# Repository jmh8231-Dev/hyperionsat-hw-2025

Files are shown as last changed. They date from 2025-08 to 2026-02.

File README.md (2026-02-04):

# HyperionSAT Flight‑Computer – 하드웨어 (2025)

> **Rev**: 1.0 · **ECAD**: KiCad 9.0.4 · **MCU**: STM32H723VGT6 (550 MHz, DP‑FPU)  
> **역할**: 2차 추진, TVC 제어, 센싱, 통신을 담당하는 하이브리드 비행 컴퓨터

---

<h3>3D Rendering</h3>
<table>
  <tr>
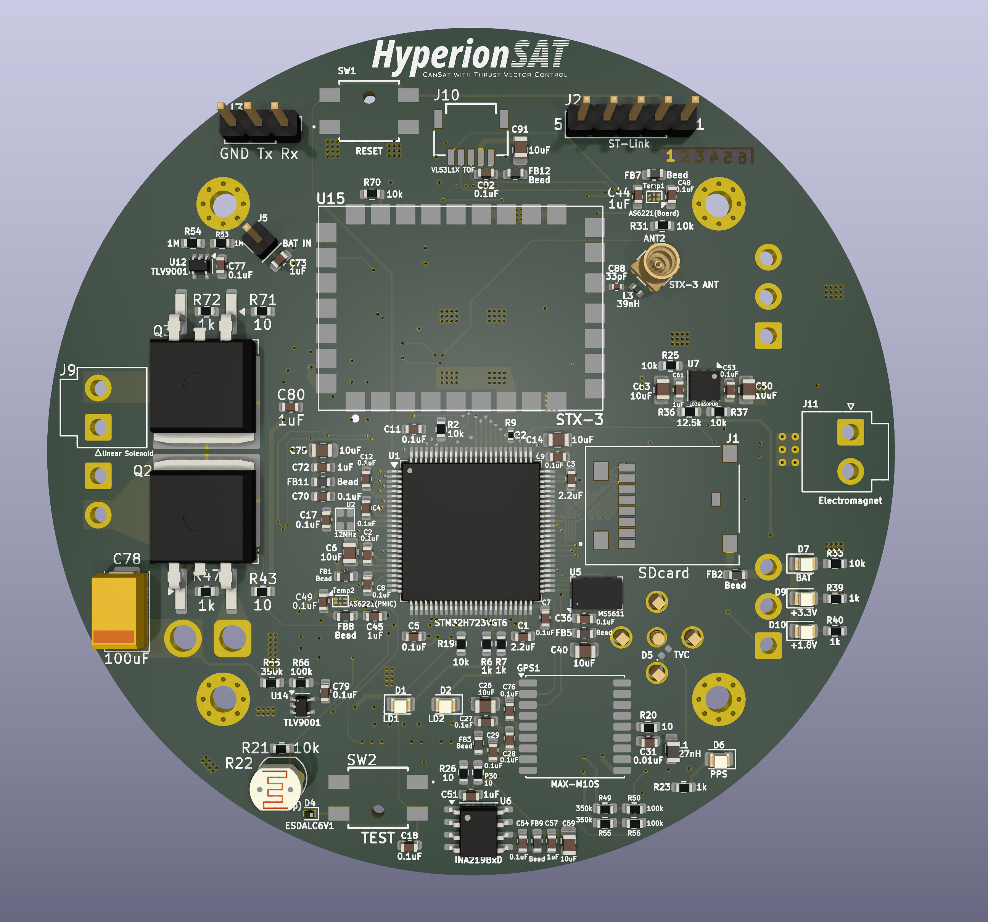
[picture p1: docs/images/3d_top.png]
Top
    <td></td>
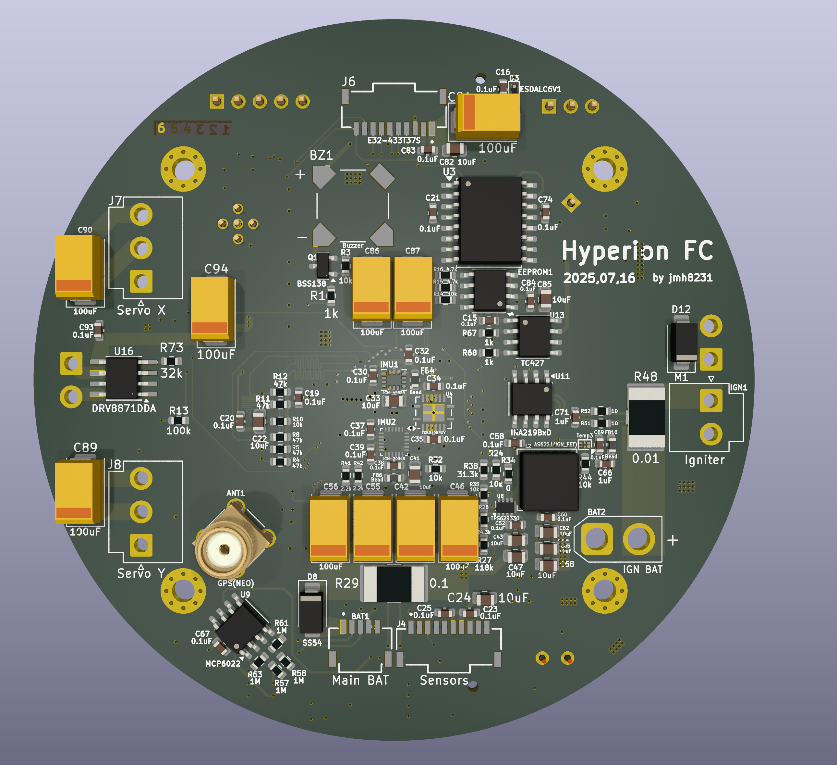
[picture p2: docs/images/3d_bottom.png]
Bottom
    <td></td>
  </tr>
  <tr>
    <td align="center"><sub>Top</sub></td>
    <td align="center"><sub>Bottom</sub></td>
  </tr>

  <tr>
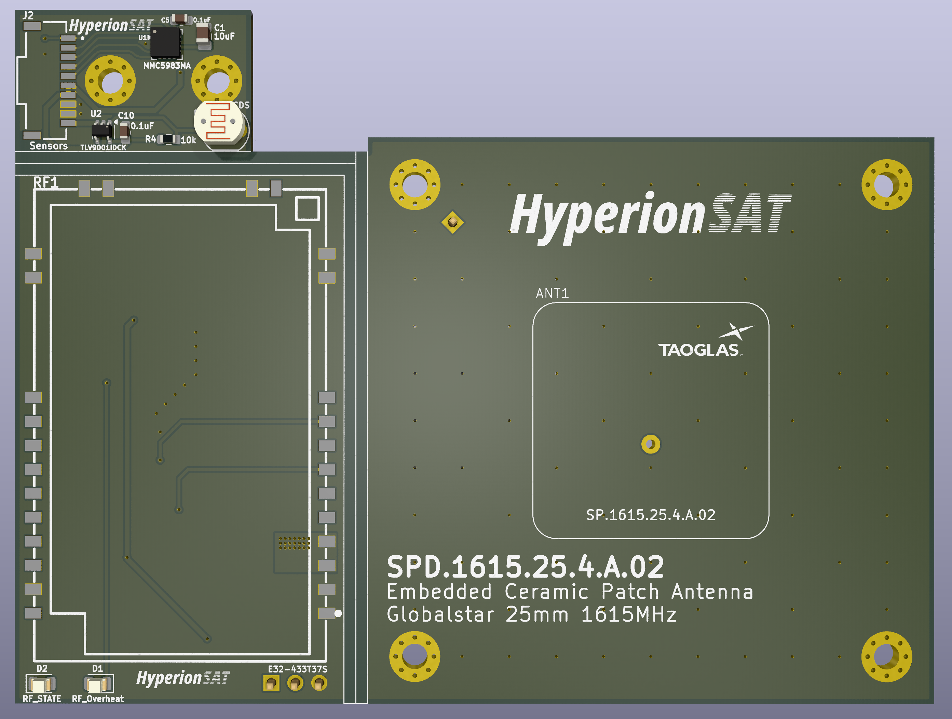
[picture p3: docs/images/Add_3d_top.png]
SUB Top
    <td></td>
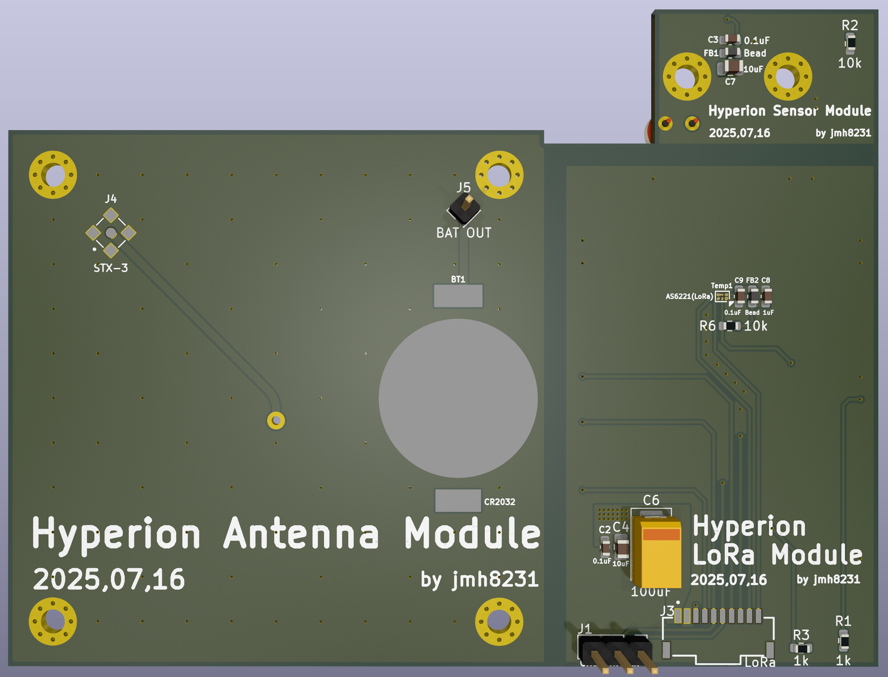
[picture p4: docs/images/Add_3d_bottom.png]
SUB Bottom
    <td></td>
  </tr>
  <tr>
    <td align="center"><sub>SUB Top</sub></td>
    <td align="center"><sub>SUB Bottom</sub></td>
  </tr>
</table>

---

## 리포지토리 구성 (스냅샷)
```
docs/
└─ images/
   ├─ sch_processor.png
   ├─ sch_sensors.png
   ├─ sch_pmic.png
   ├─ sch_comm.png
   ├─ sch_actuators.png
   └─ sch_additional.png
README.md
```

---

## 1) 시스템 개요

**블록**
- **Processor**: STM32H723VGT6, 12 MHz TCXO, SWD, EEPROM(AT24C08C), RTC(DS3231M), Buzzer/LED, microSD(SDMMC 4‑bit).
- **Flight Sensors**: ICM‑45686(SPI), ICM‑20948(SPI, 1.8 V IO), MS5611(SPI), MMC5983MA(SPI), MAX‑M10S(UART+PPS), VL53L1X(I²C), **CDS‑Top/Bottom**(Bottom=TLV9001 버퍼).
- **Actuators**: TVC 서보 X/Y(12 V), **리니어 솔레노이드**(IRF1404, 어댑터 분리), **낙하산 전개 전자석**(DRV8871DDA).
- **Communications**: LoRa E32‑433T37S(UART + M0/M1/AUX), **Globalstar STX‑3**(UART + EN/RESET), RF 매칭 네트워크.
- **PMIC/Power**: 메인 Li‑Po 3S(셀1/2 버퍼드 ADC), **점화 배터리**(팩 전압 ADC), 3.3 V 스위칭, **INA219** 방전/점화 전류 측정, **AS6221** 온도.

**점화(IGN)**: **1채널** 구성으로 단순화됨.

<h3>Block Diagrams</h3>
<table>
  <tr>
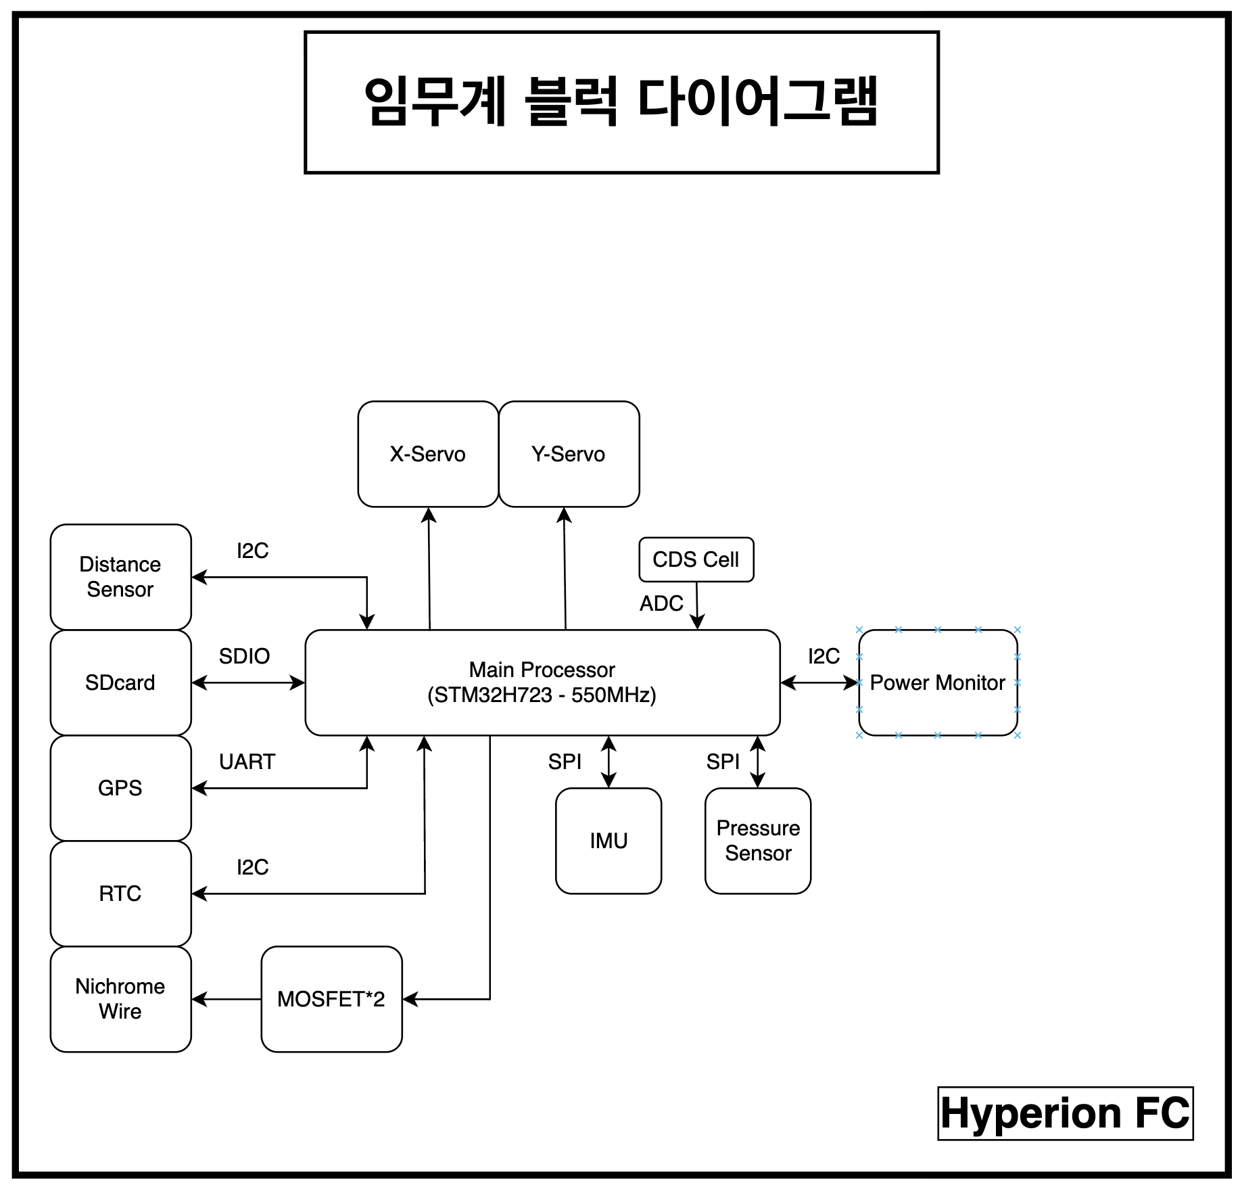
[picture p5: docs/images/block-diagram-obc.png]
OBC
    <td></td>
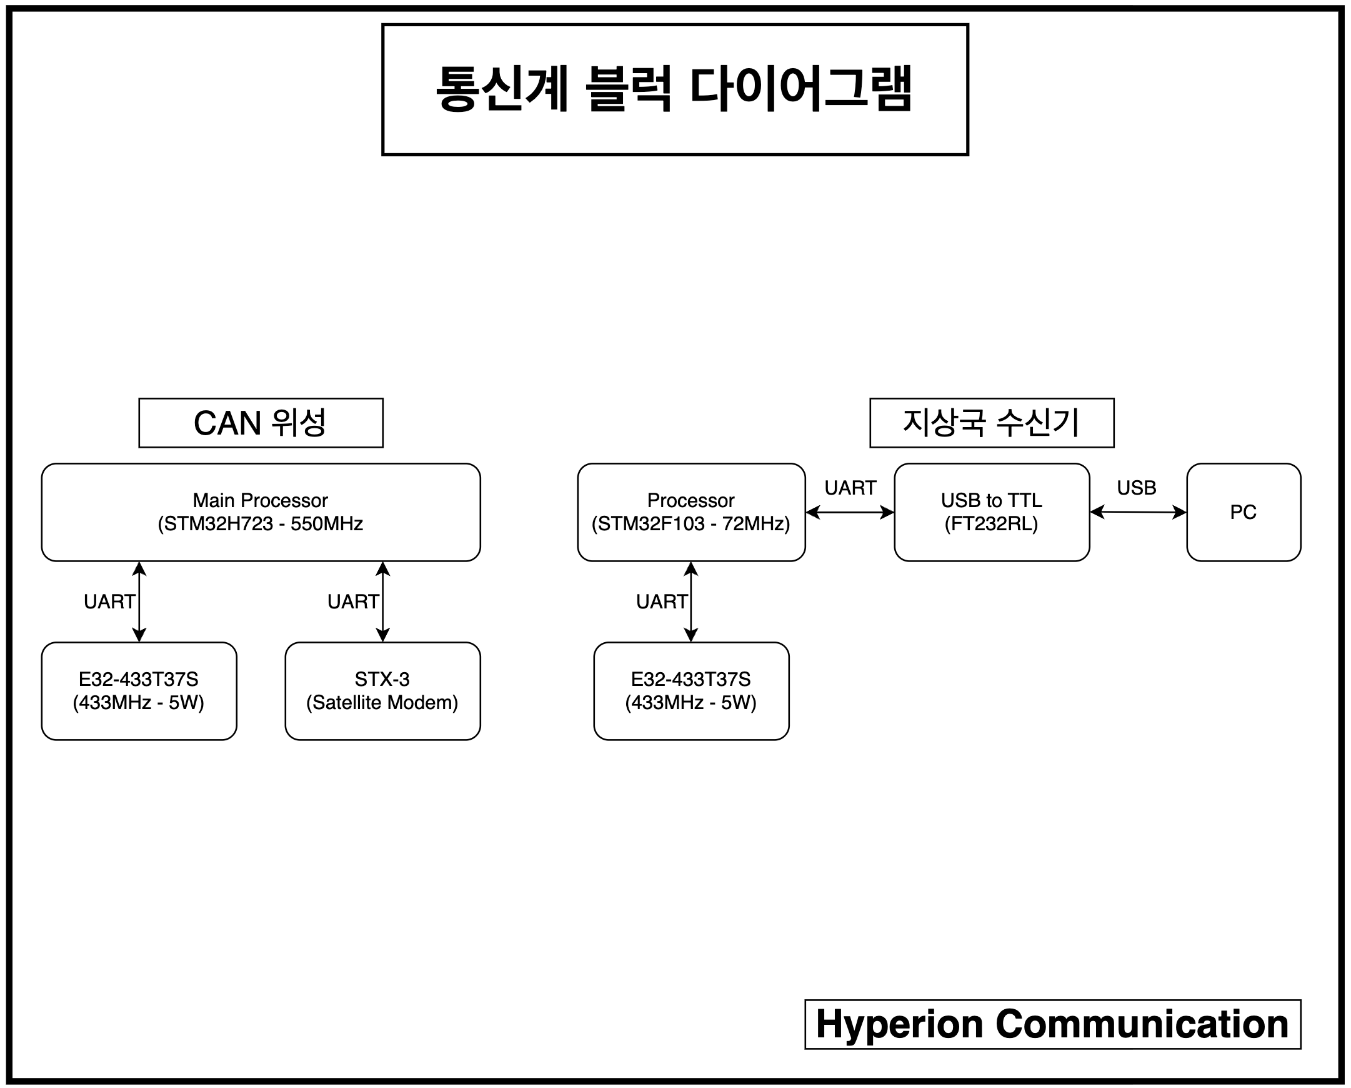
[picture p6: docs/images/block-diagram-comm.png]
Communication
    <td></td>
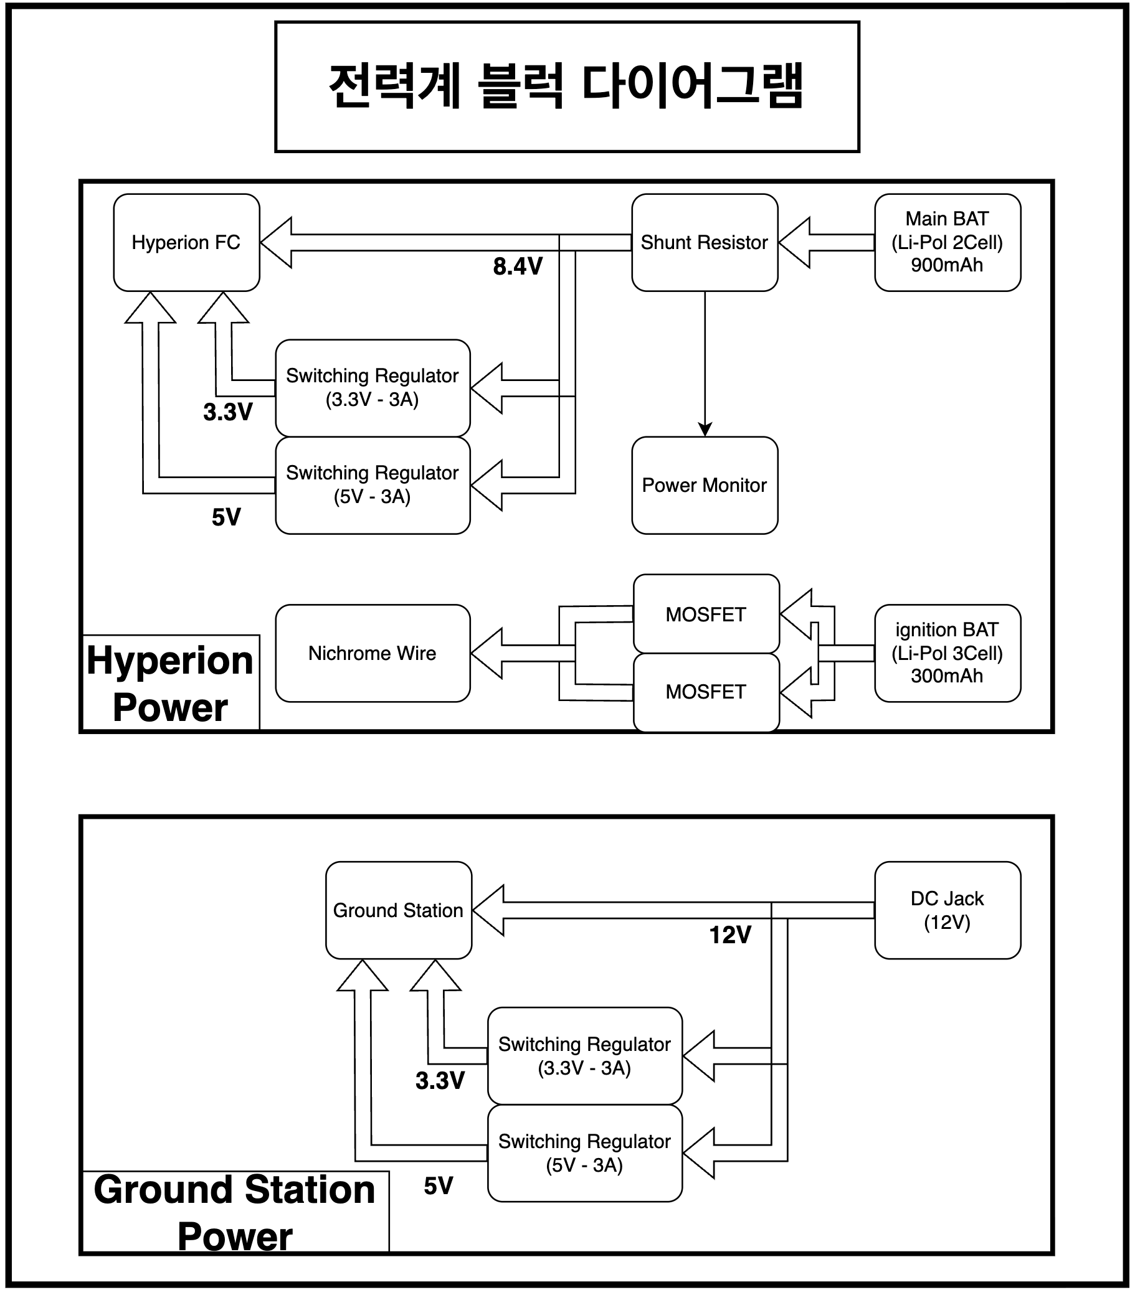
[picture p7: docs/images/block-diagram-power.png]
Power
    <td></td>
  </tr>
  <tr>
    <td align="center"><sub>OBC</sub></td>
    <td align="center"><sub>Communication</sub></td>
    <td align="center"><sub>Power</sub></td>
  </tr>
</table>

---

## 2) 전기적 인터페이스 (네트 라벨 기준)

### SPI
| Bus | Device | Signals |
|---|---|---|
| SPI‑A | ICM‑45686 | `ICM-45686_SCK/MISO/MOSI/CS`, `ICM-45686_INT` |
| SPI‑B | ICM‑20948, MS5611 | `ICM-20948_SCK/MISO/MOSI/CS`, `IMU2_INT`; `Barometer_SCK/MISO/MOSI/CS` |
| SPI‑C | MMC5983MA | `MMC5983MA_SCK/MISO/MOSI/CS`, `MMC5983MA_INT` |

### I²C (7‑bit)
| Bus | Device | Addr |
|---|---|---|
| RTC | DS3231M | 0x68 |
| EEPROM | AT24C08C | 0x50 *(데이터시트 8‑bit 코드 0xA0)* |
| TEMP | AS6221(Board/PMIC/FET/LoRa) | 0x48 / 0x49 / 0x4B / 0x4A |
| IGN | INA219 | 0x41 |

### UART / 타이밍 / GPIO
| Link | Signals |
|---|---|
| Debug | `Debug_Tx`, `Debug_Rx` |
| LoRa(E32) | `RF_Tx`, `RF_Rx`, `RF_M0`, `RF_M1`, `RF_AUX` |
| STX‑3 | `STX-3_Tx`, `STX-3_Rx`, `STX-3_CTS`, `STX-3_RTS`, `STX-3_EN`, `STX-3_Reset` |
| GPS | `GPS_Tx`, `GPS_Rx`, `GPS_PPS` |
| SDMMC | `SDMMC_D0..D3`, `SDMMC_CLK`, `SDMMC_CMD`, `SDMMC_DET`, `SDMMC_WP` |
| Actuators | `Servo_X`, `Servo_Y`, `Solenoid_Gate`, `DRV8871_A`, `DRV8871_B` |
| Analog | `Main_Cell1_ADC`, `Main_Cell2_ADC`, `IGN_BAT_ADC`, `Back-up_BAT_ADC`, `CDS_Top`, `CDS_Bottom_ADC` |

---

## 3) 회로도 스냅샷

- **Processor**  
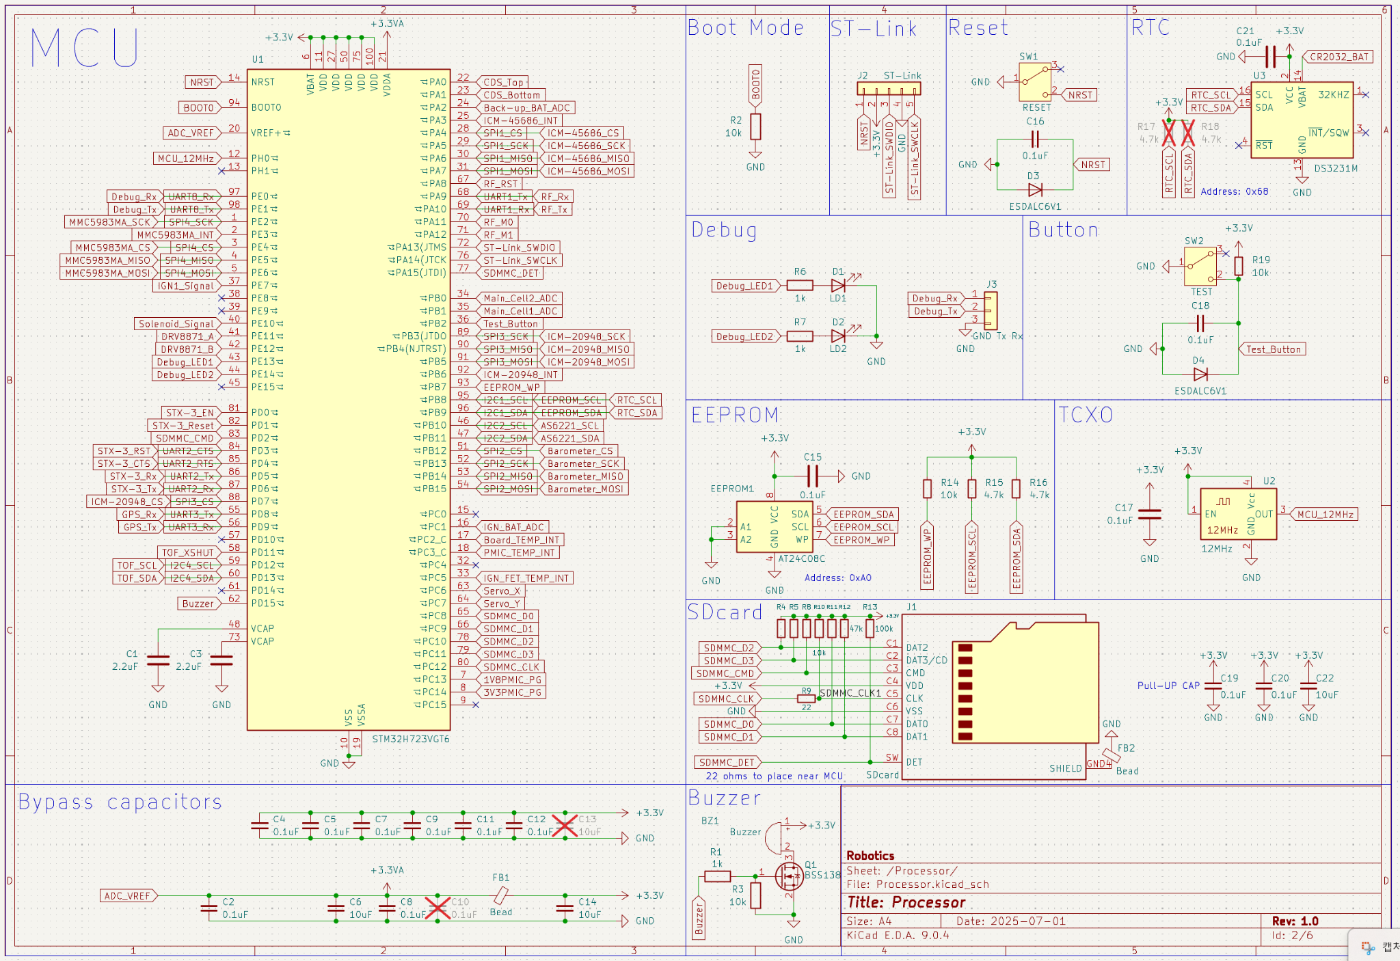
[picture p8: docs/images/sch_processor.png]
  

- **Flight Sensors**  
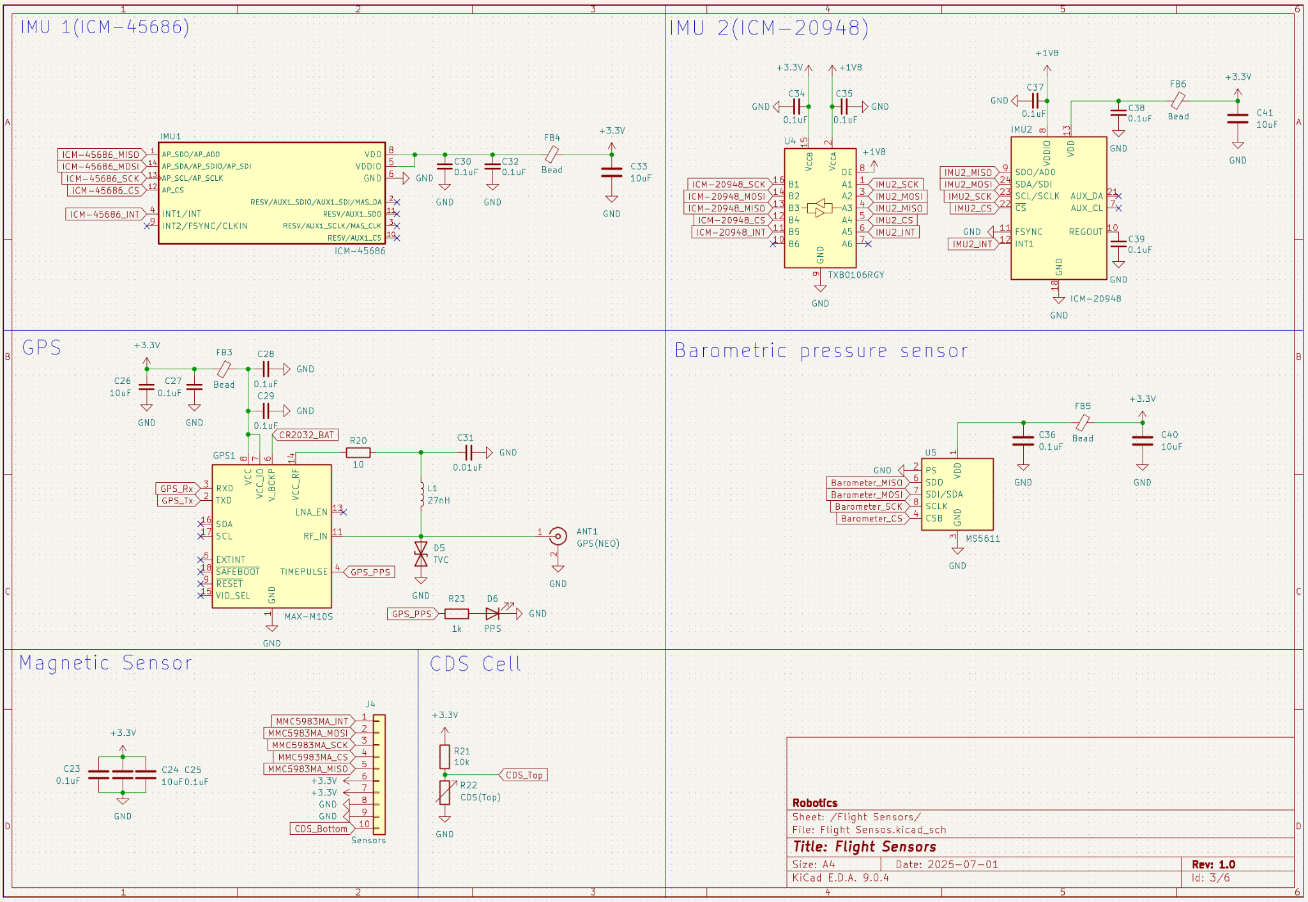
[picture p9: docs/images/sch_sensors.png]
  

- **PMIC / Power**  
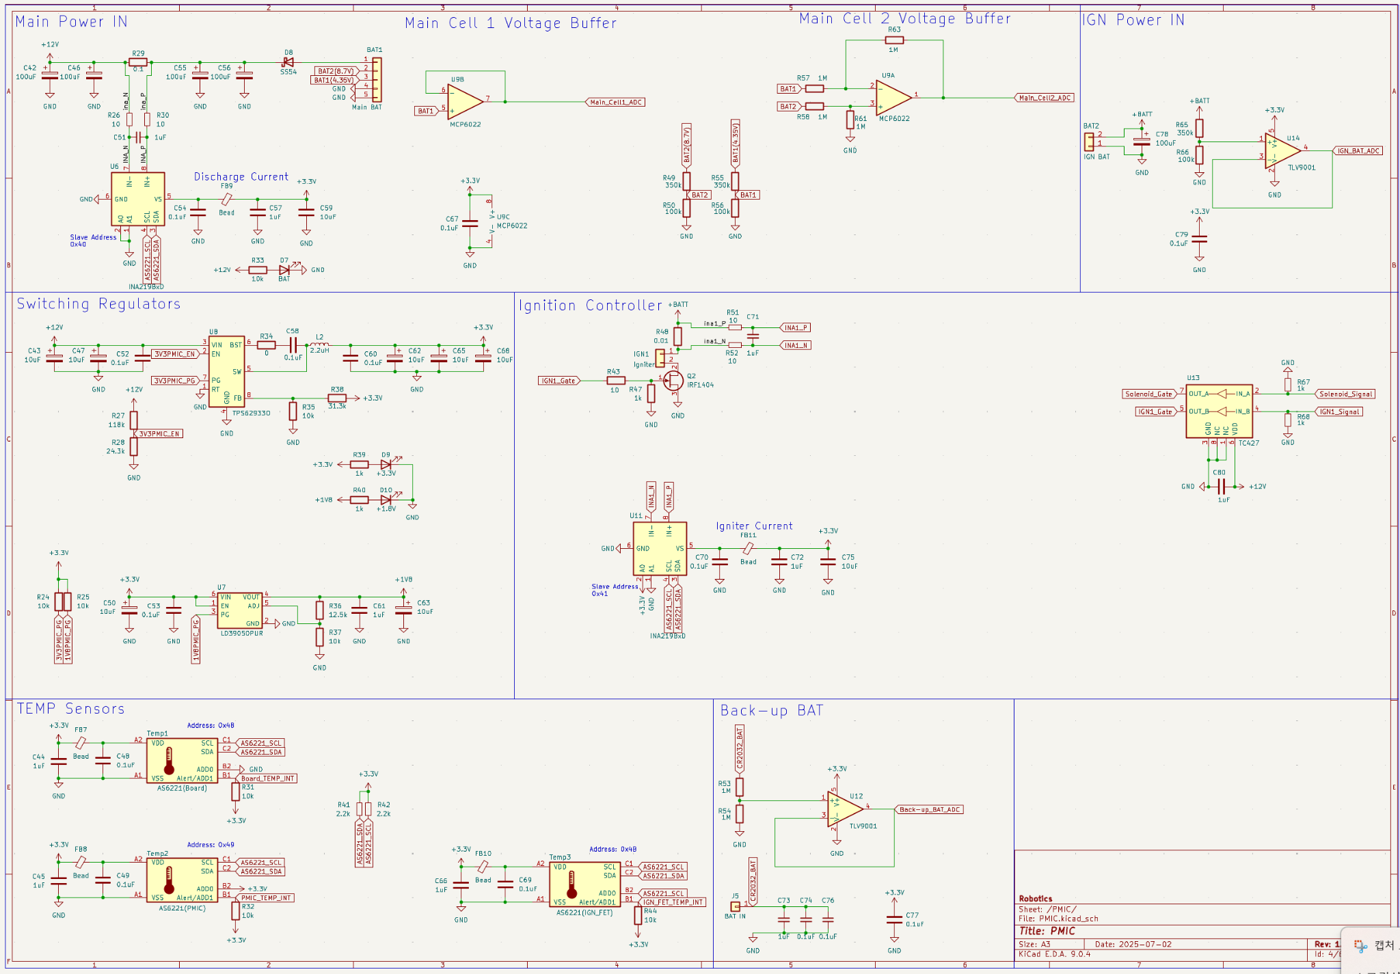
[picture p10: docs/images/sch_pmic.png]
  

- **Communications**  
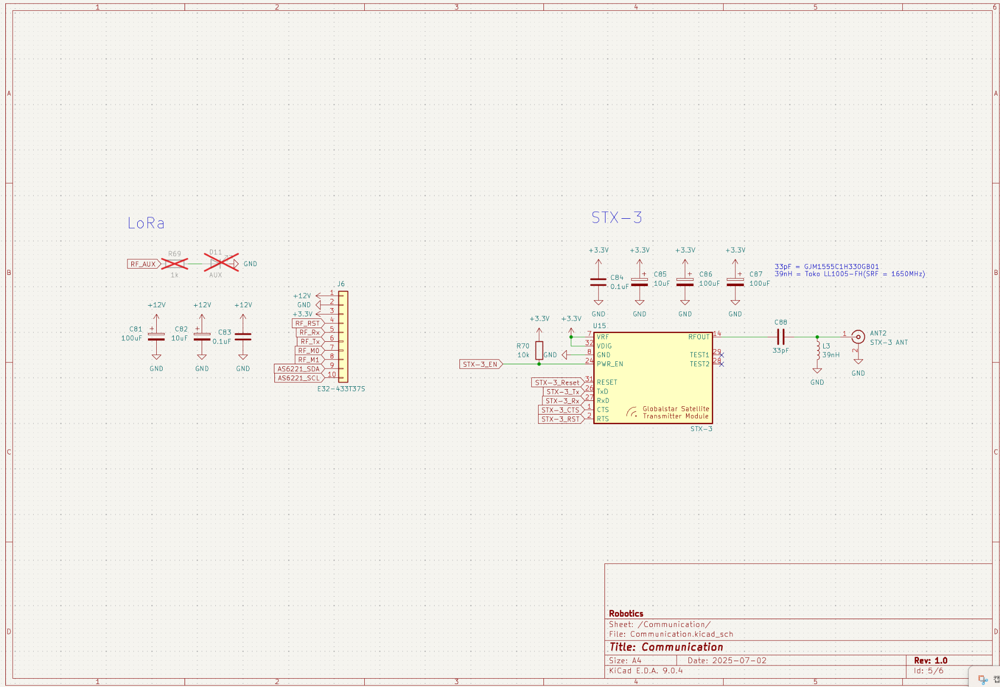
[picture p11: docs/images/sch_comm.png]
  

- **Actuators**  
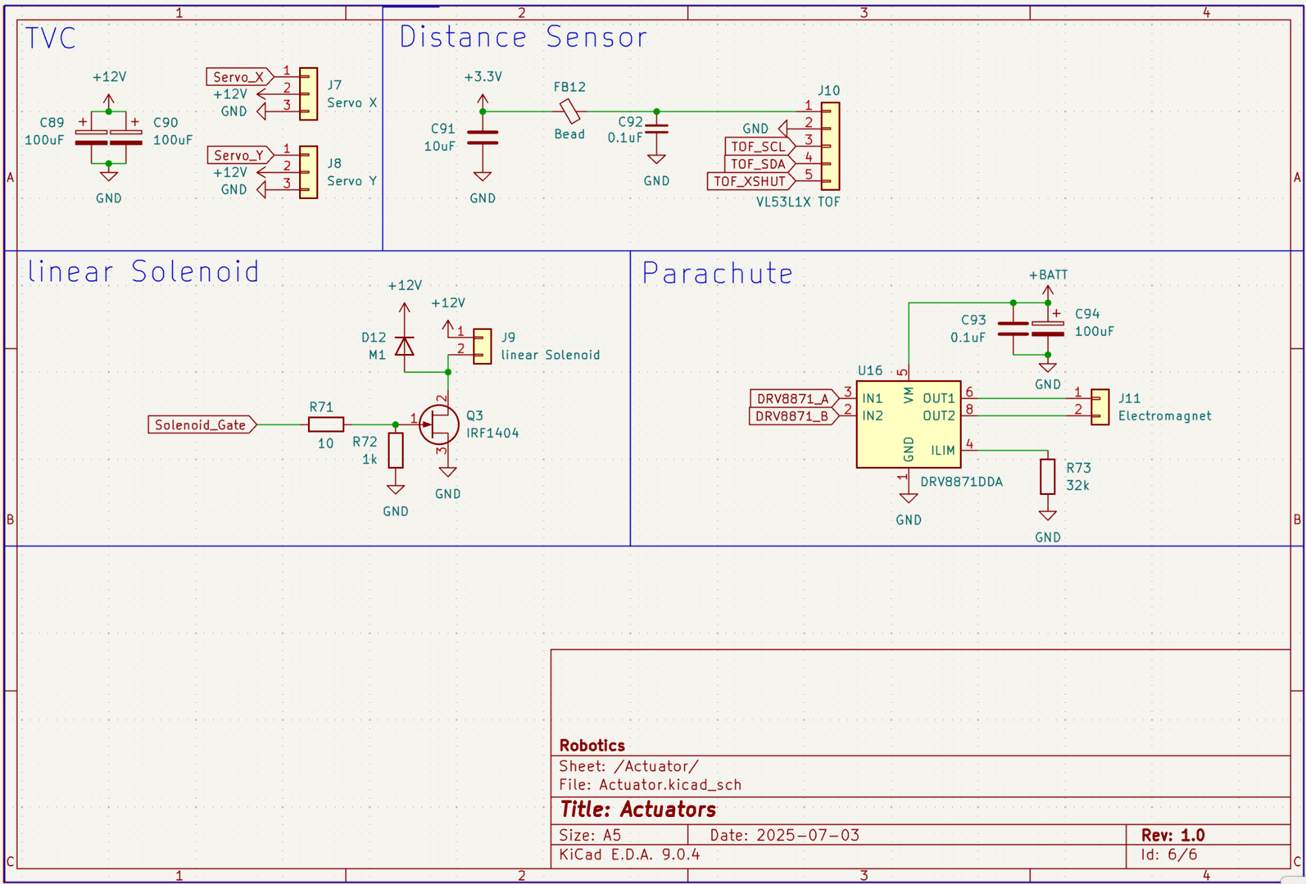
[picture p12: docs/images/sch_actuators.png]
  

- **Additional parts (Magnetometer SPI, CDS Bottom 버퍼, LoRa 온도)**  
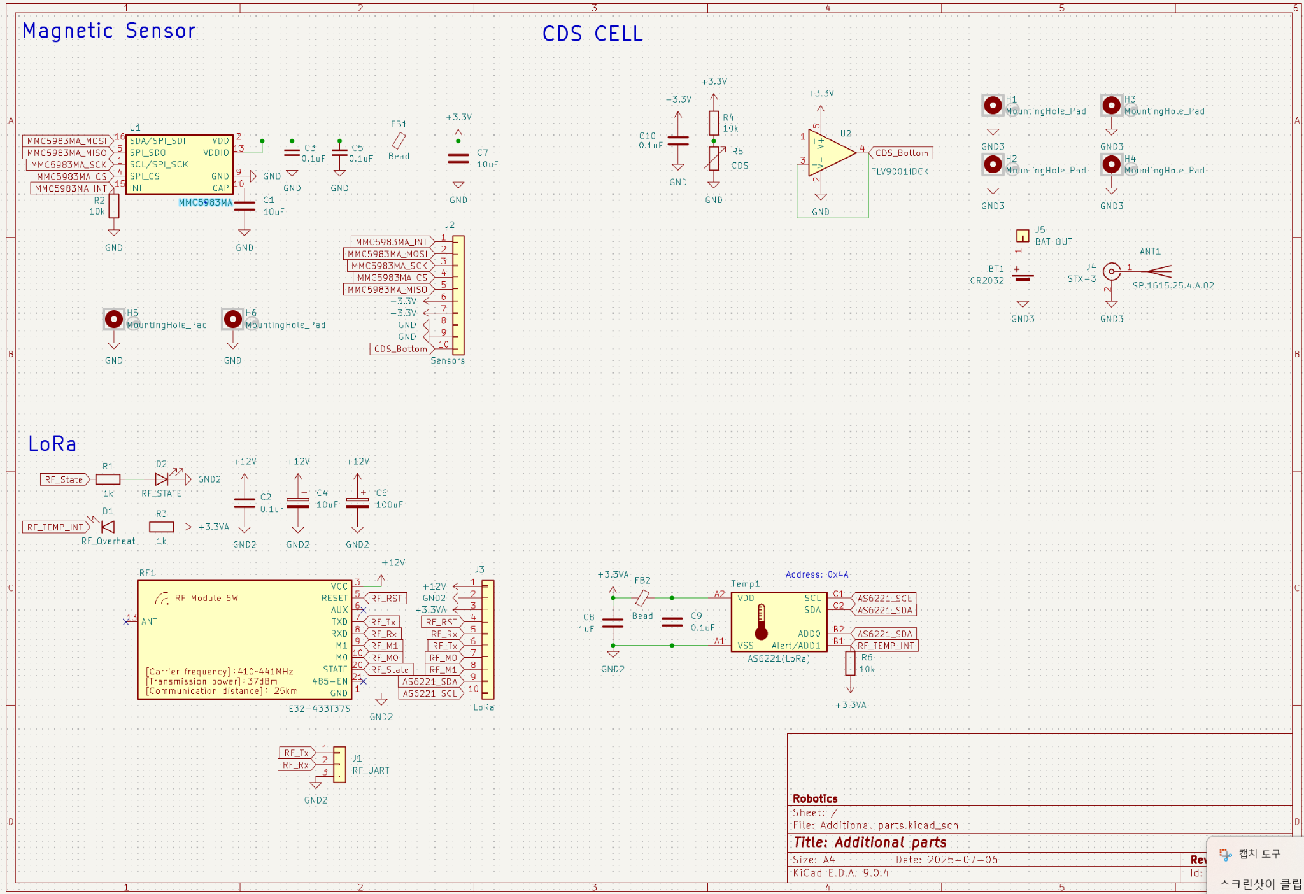
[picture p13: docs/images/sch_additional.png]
  

> **Firmware repo**: [https://github.com/ORG/REPO-FW  ](https://github.com/jmh8231-Dev/hyperionsat-fw-2025)

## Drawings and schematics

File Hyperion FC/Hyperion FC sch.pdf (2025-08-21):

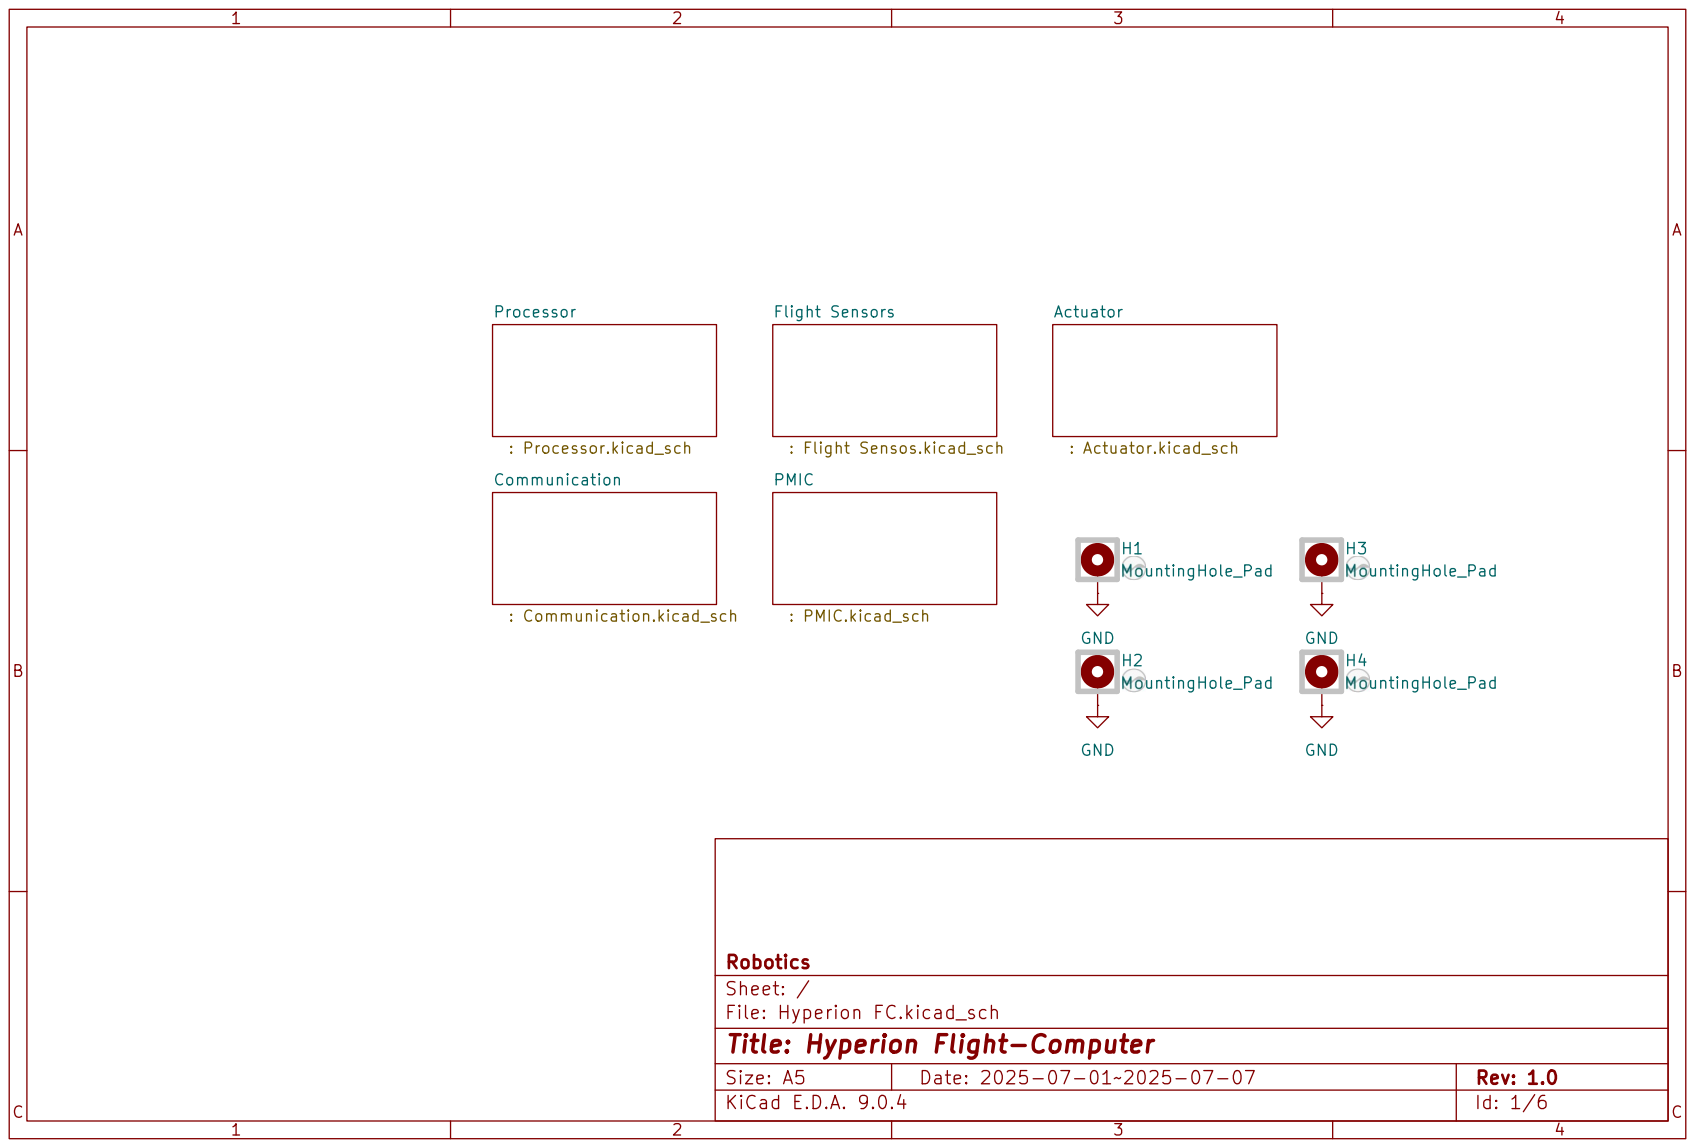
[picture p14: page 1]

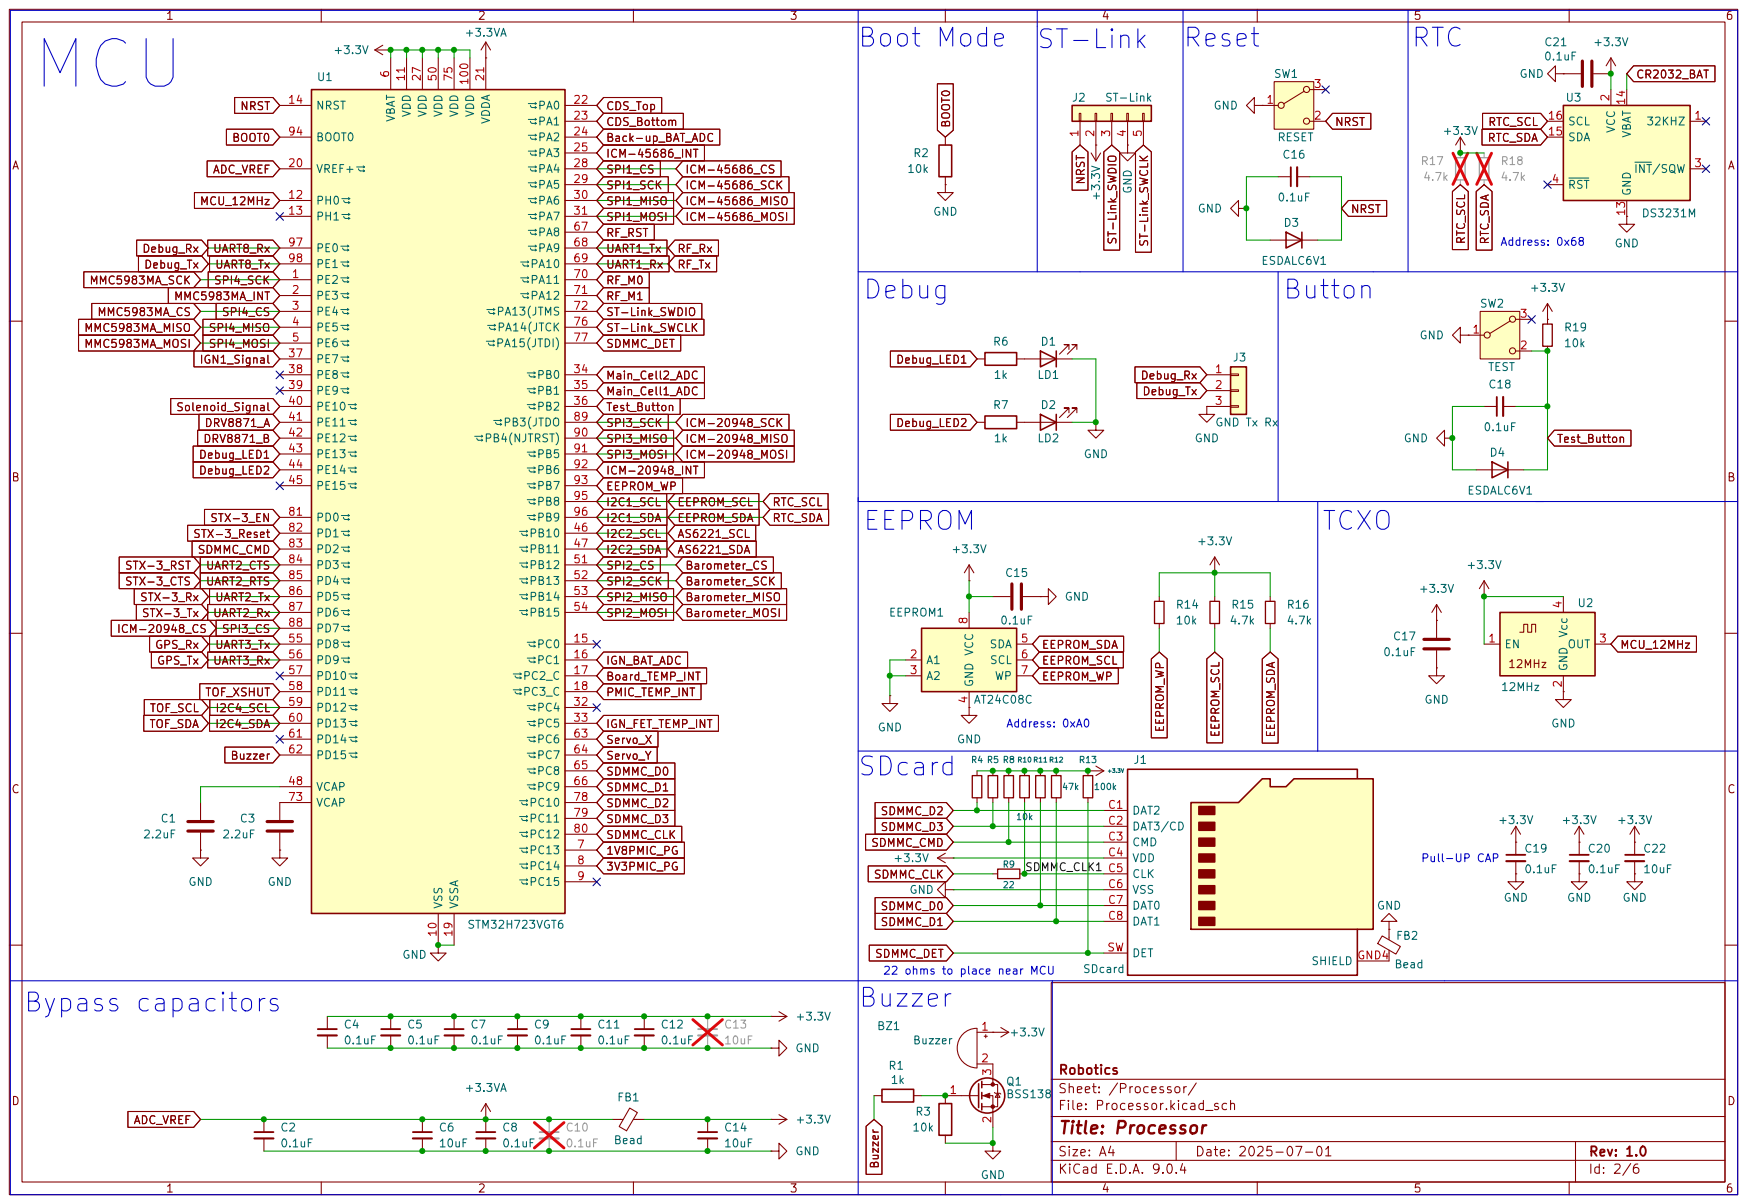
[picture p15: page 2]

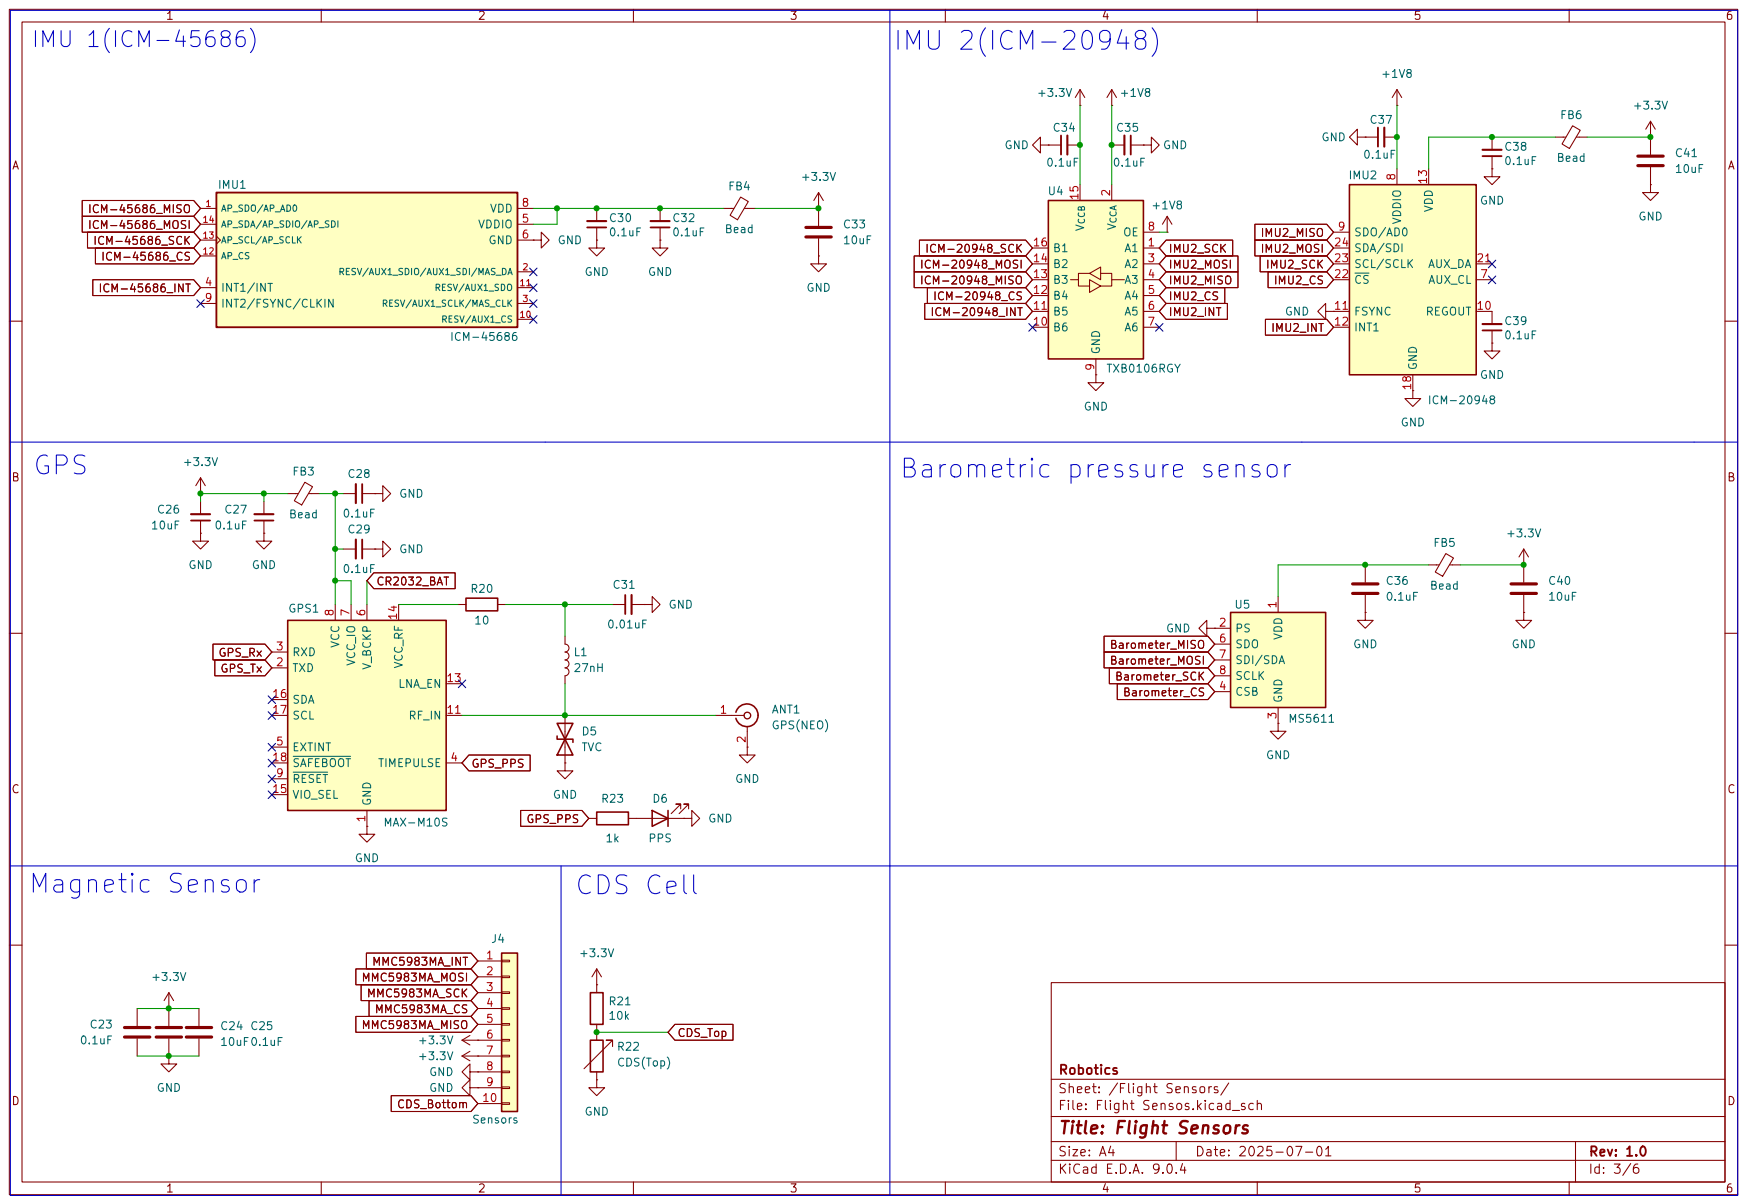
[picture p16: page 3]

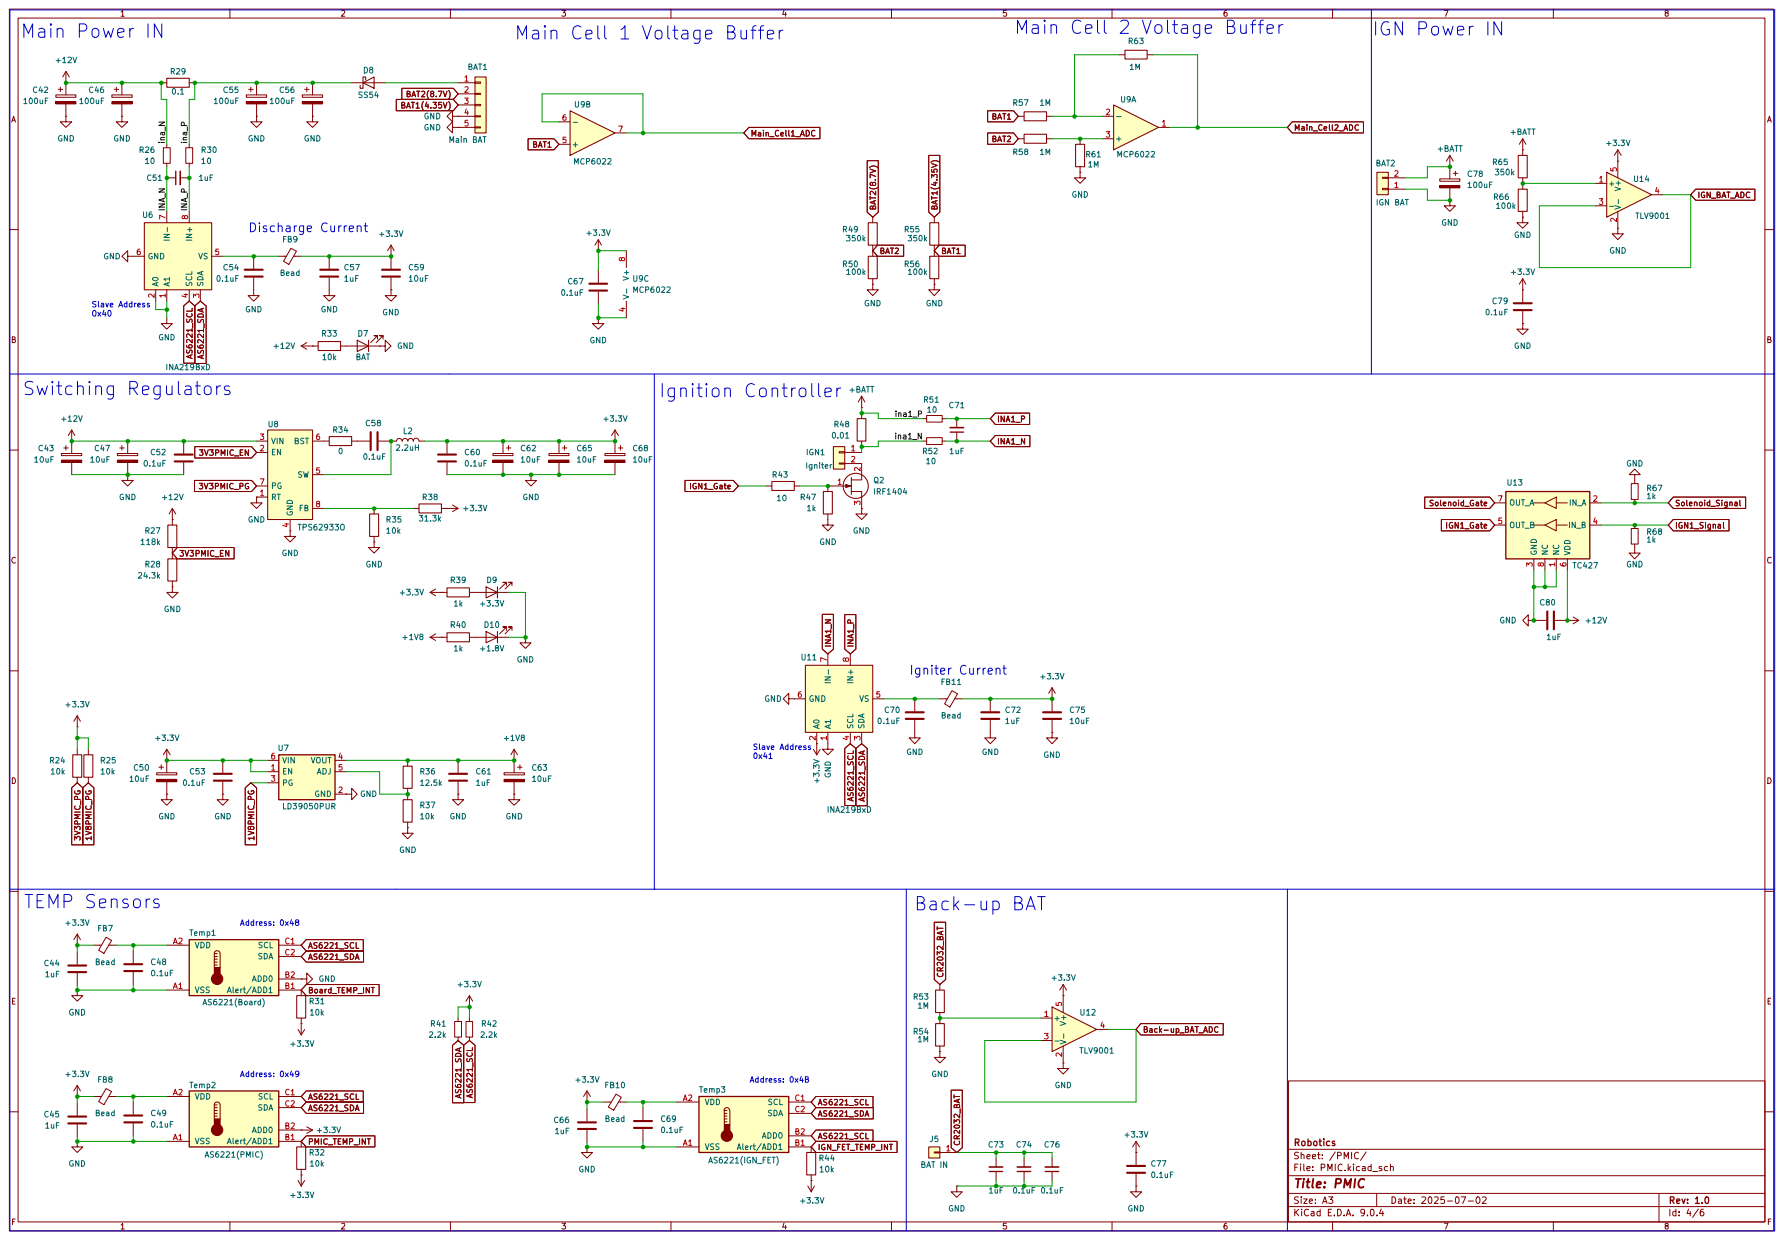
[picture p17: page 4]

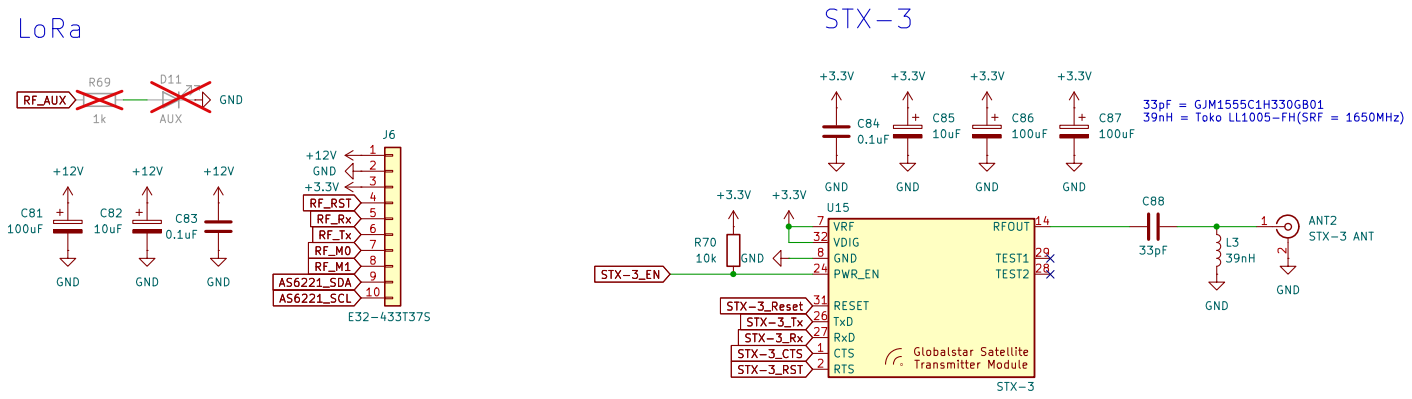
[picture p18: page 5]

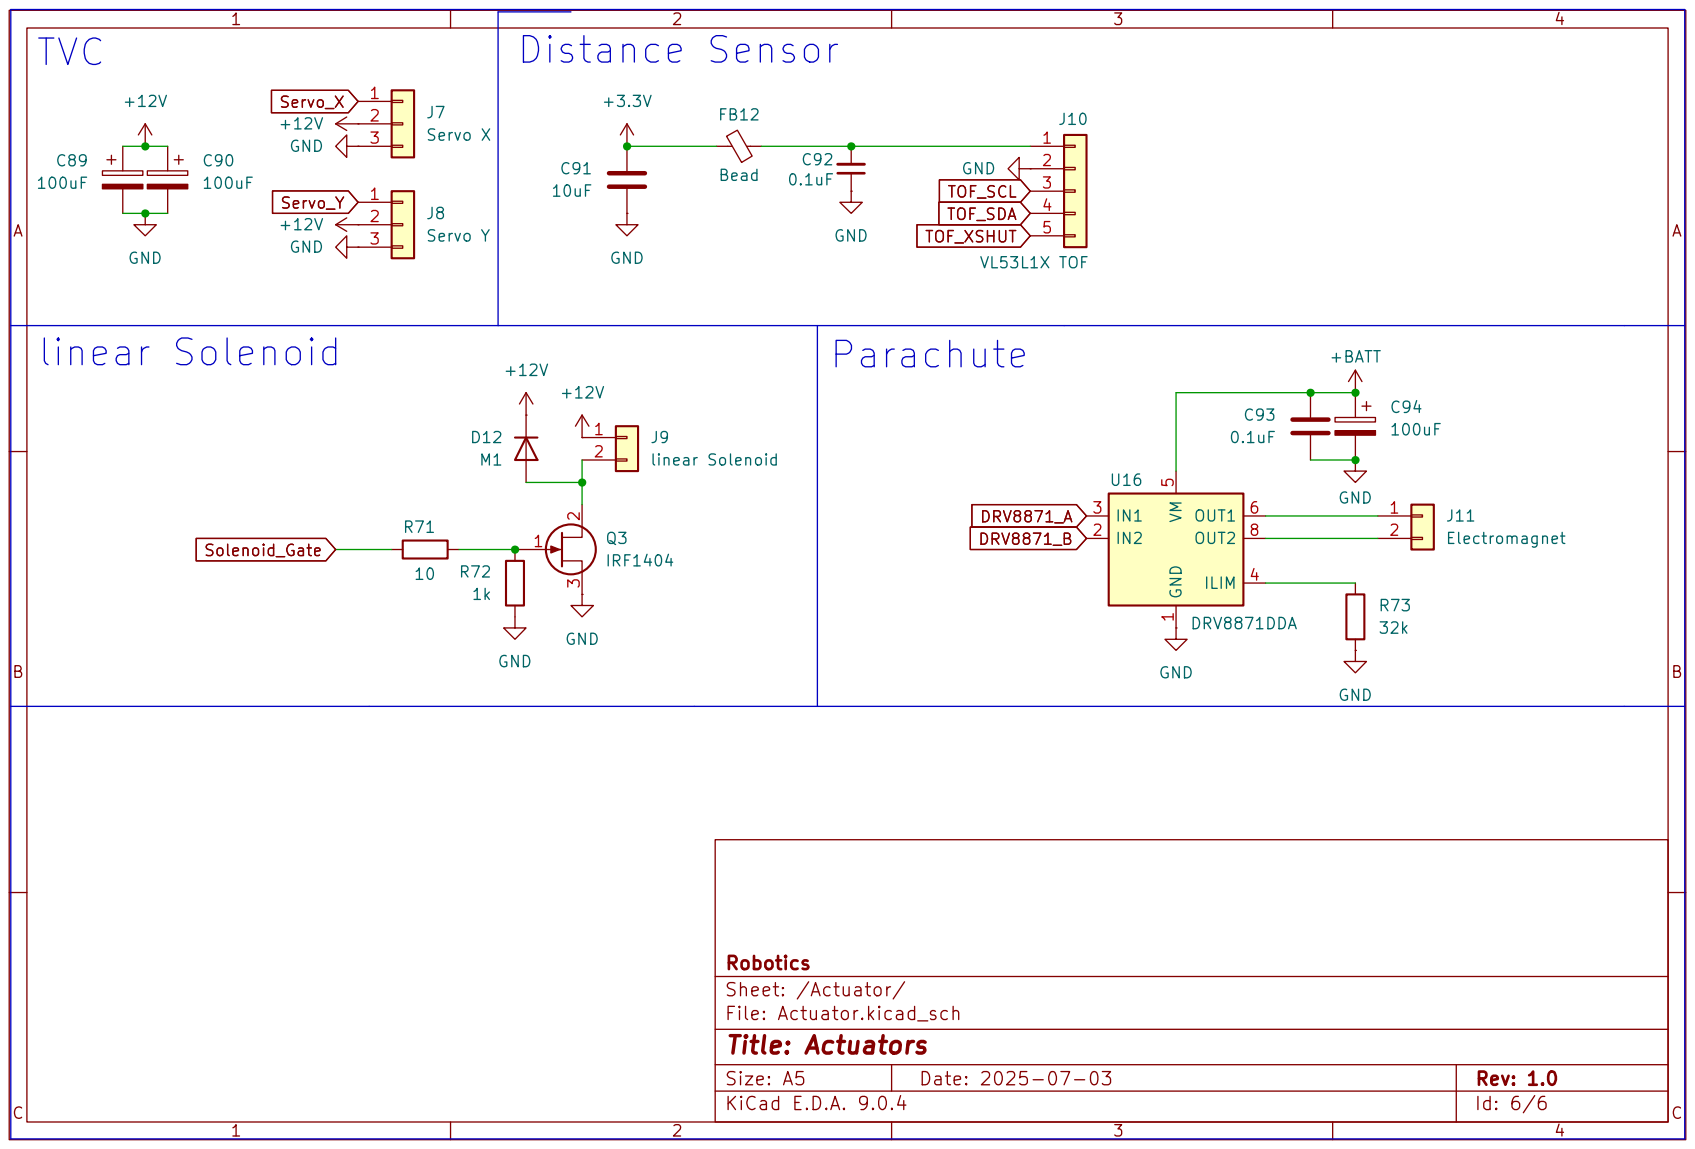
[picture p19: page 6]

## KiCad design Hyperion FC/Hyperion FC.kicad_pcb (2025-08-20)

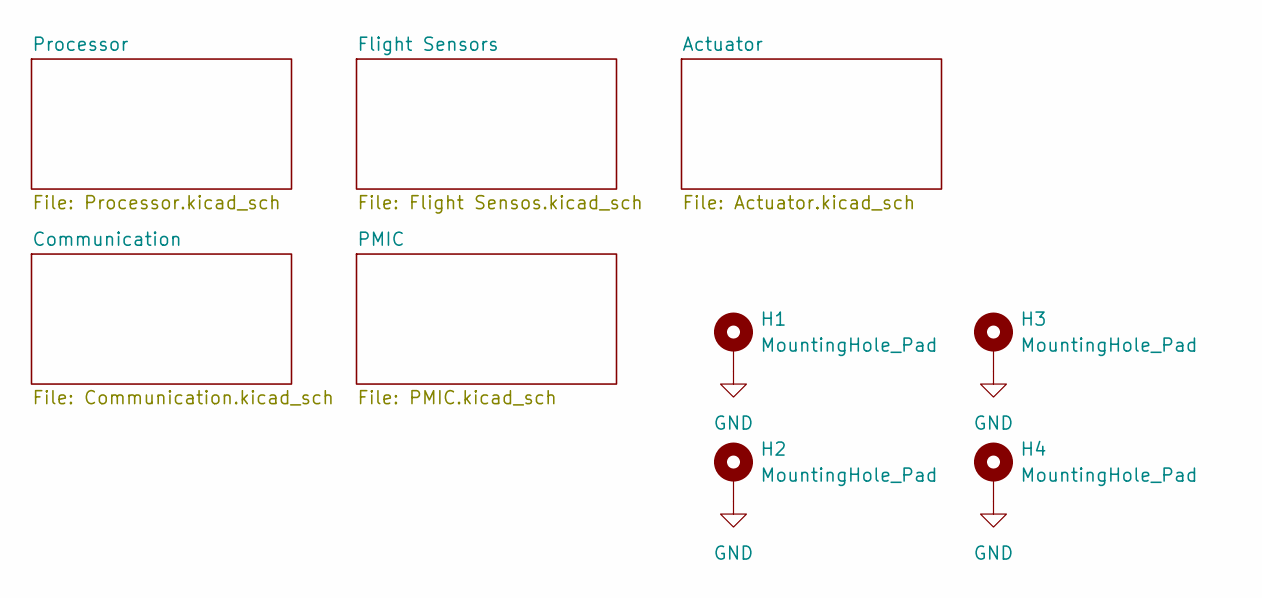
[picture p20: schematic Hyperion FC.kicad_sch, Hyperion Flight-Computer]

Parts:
H1, H2, H3, H4: MountingHole_Pad; MountingHole_2.7mm_M2.5_Pad_Via

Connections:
GND: H1.1, H2.1, H3.1, H4.1; also elsewhere on the board

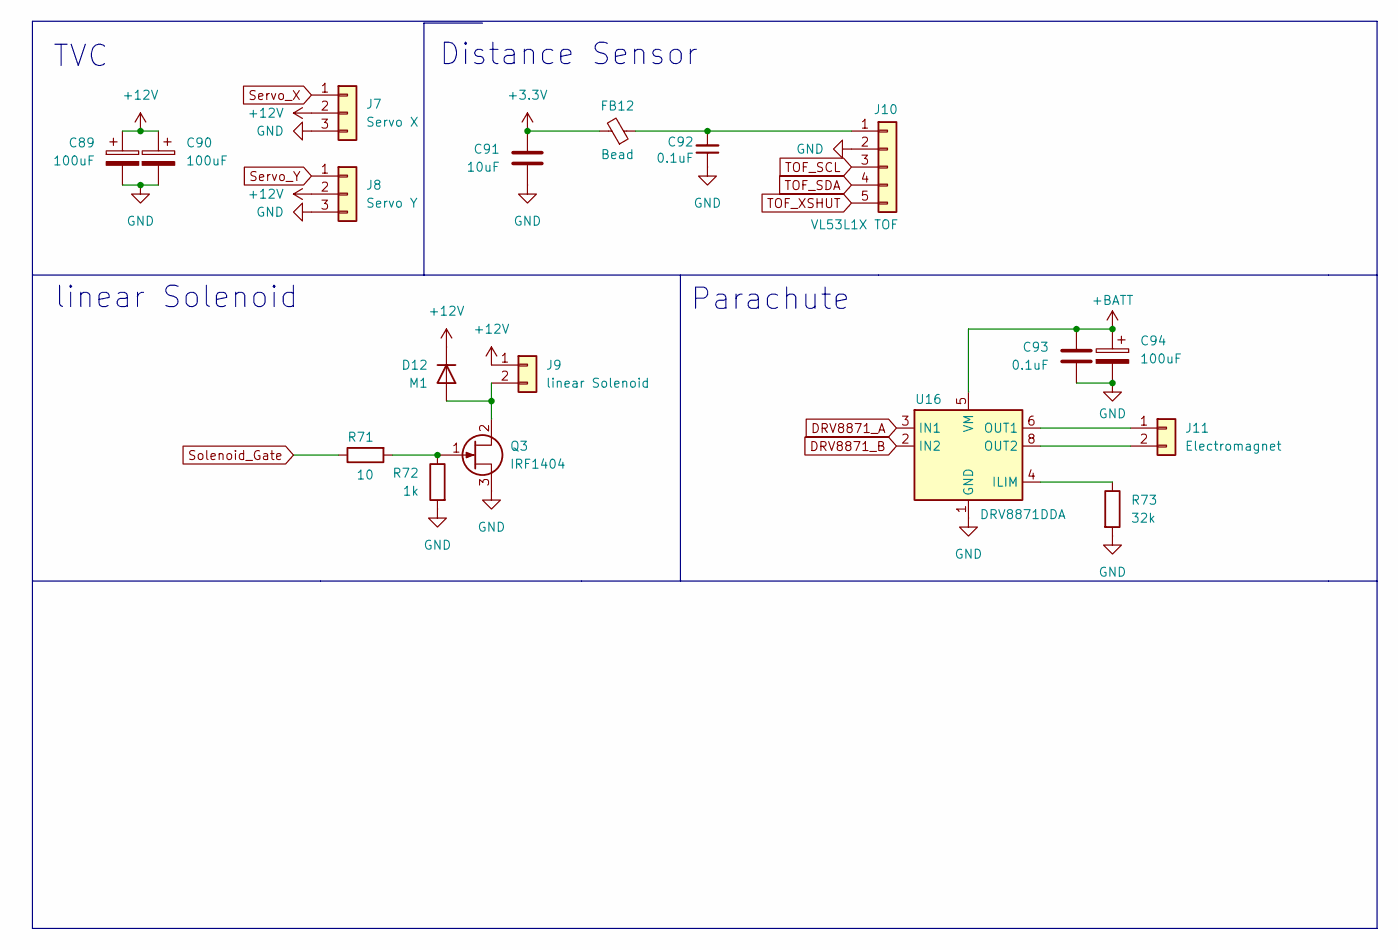
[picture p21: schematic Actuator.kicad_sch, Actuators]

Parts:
C89, C90, C94: 100uF; CP_EIA-7343-43_Kemet-X
C91: 10uF; C_0805_2012Metric
C92, C93: 0.1uF; C_0603_1608Metric
D12: M1; D_SMA
FB12: Bead; L_0603_1608Metric
J7: Servo X; JST_VH_B3P-VH_1x03_P3.96mm_Vertical
J8: Servo Y; JST_VH_B3P-VH_1x03_P3.96mm_Vertical
J9: linear Solenoid; JST_VH_B2P-VH_1x02_P3.96mm_Vertical
J10: VL53L1X TOF; SAMTEC_T1M-05-F-SH-L
J11: Electromagnet; JST_VH_B2P-VH_1x02_P3.96mm_Vertical
Q3: IRF1404; TO-263-2
R71: 10; R_0603_1608Metric
R72: 1k; R_0603_1608Metric
R73: 32k; R_0603_1608Metric
U16: DRV8871DDA; Texas_HTSOP-8-1EP_3.9x4.9mm_P1.27mm_EP2.95x4.9mm_Mask2.4x3.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

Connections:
+3.3V: C91.1, FB12.2; also elsewhere on the board
+12V: C89.1, C90.1, D12.1 (K), J7.2, J8.2, J9.1; also elsewhere on the board
+BATT: C93.1, C94.1, U16.5 (VM); also elsewhere on the board
DRV8871_A: U16.3 (IN1); also elsewhere on the board
DRV8871_B: U16.2 (IN2); also elsewhere on the board
GND: C89.2, C90.2, C91.2, C92.1, C93.2, C94.2, J7.3, J8.3, J10.2, Q3.3 (S), R72.2, R73.2, U16.1 (GND), U16.7 (GND), U16.9 (GND); also elsewhere on the board
I2C4_SCL: J10.3; also elsewhere on the board
I2C4_SDA: J10.4; also elsewhere on the board
unnamed: D12.2 (A), J9.2, Q3.2 (D)
unnamed: C92.2, FB12.1, J10.1
unnamed: J11.1, U16.6 (OUT1)
unnamed: J11.2, U16.8 (OUT2)
unnamed: Q3.1 (G), R71.2, R72.1
unnamed: R73.1, U16.4 (ILIM)
Servo_X: J7.1; also elsewhere on the board
Servo_Y: J8.1; also elsewhere on the board
Solenoid_Gate: R71.1; also elsewhere on the board
TOF_XSHUT: J10.5; also elsewhere on the board

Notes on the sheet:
linear Solenoid
Parachute
TVC
Distance Sensor

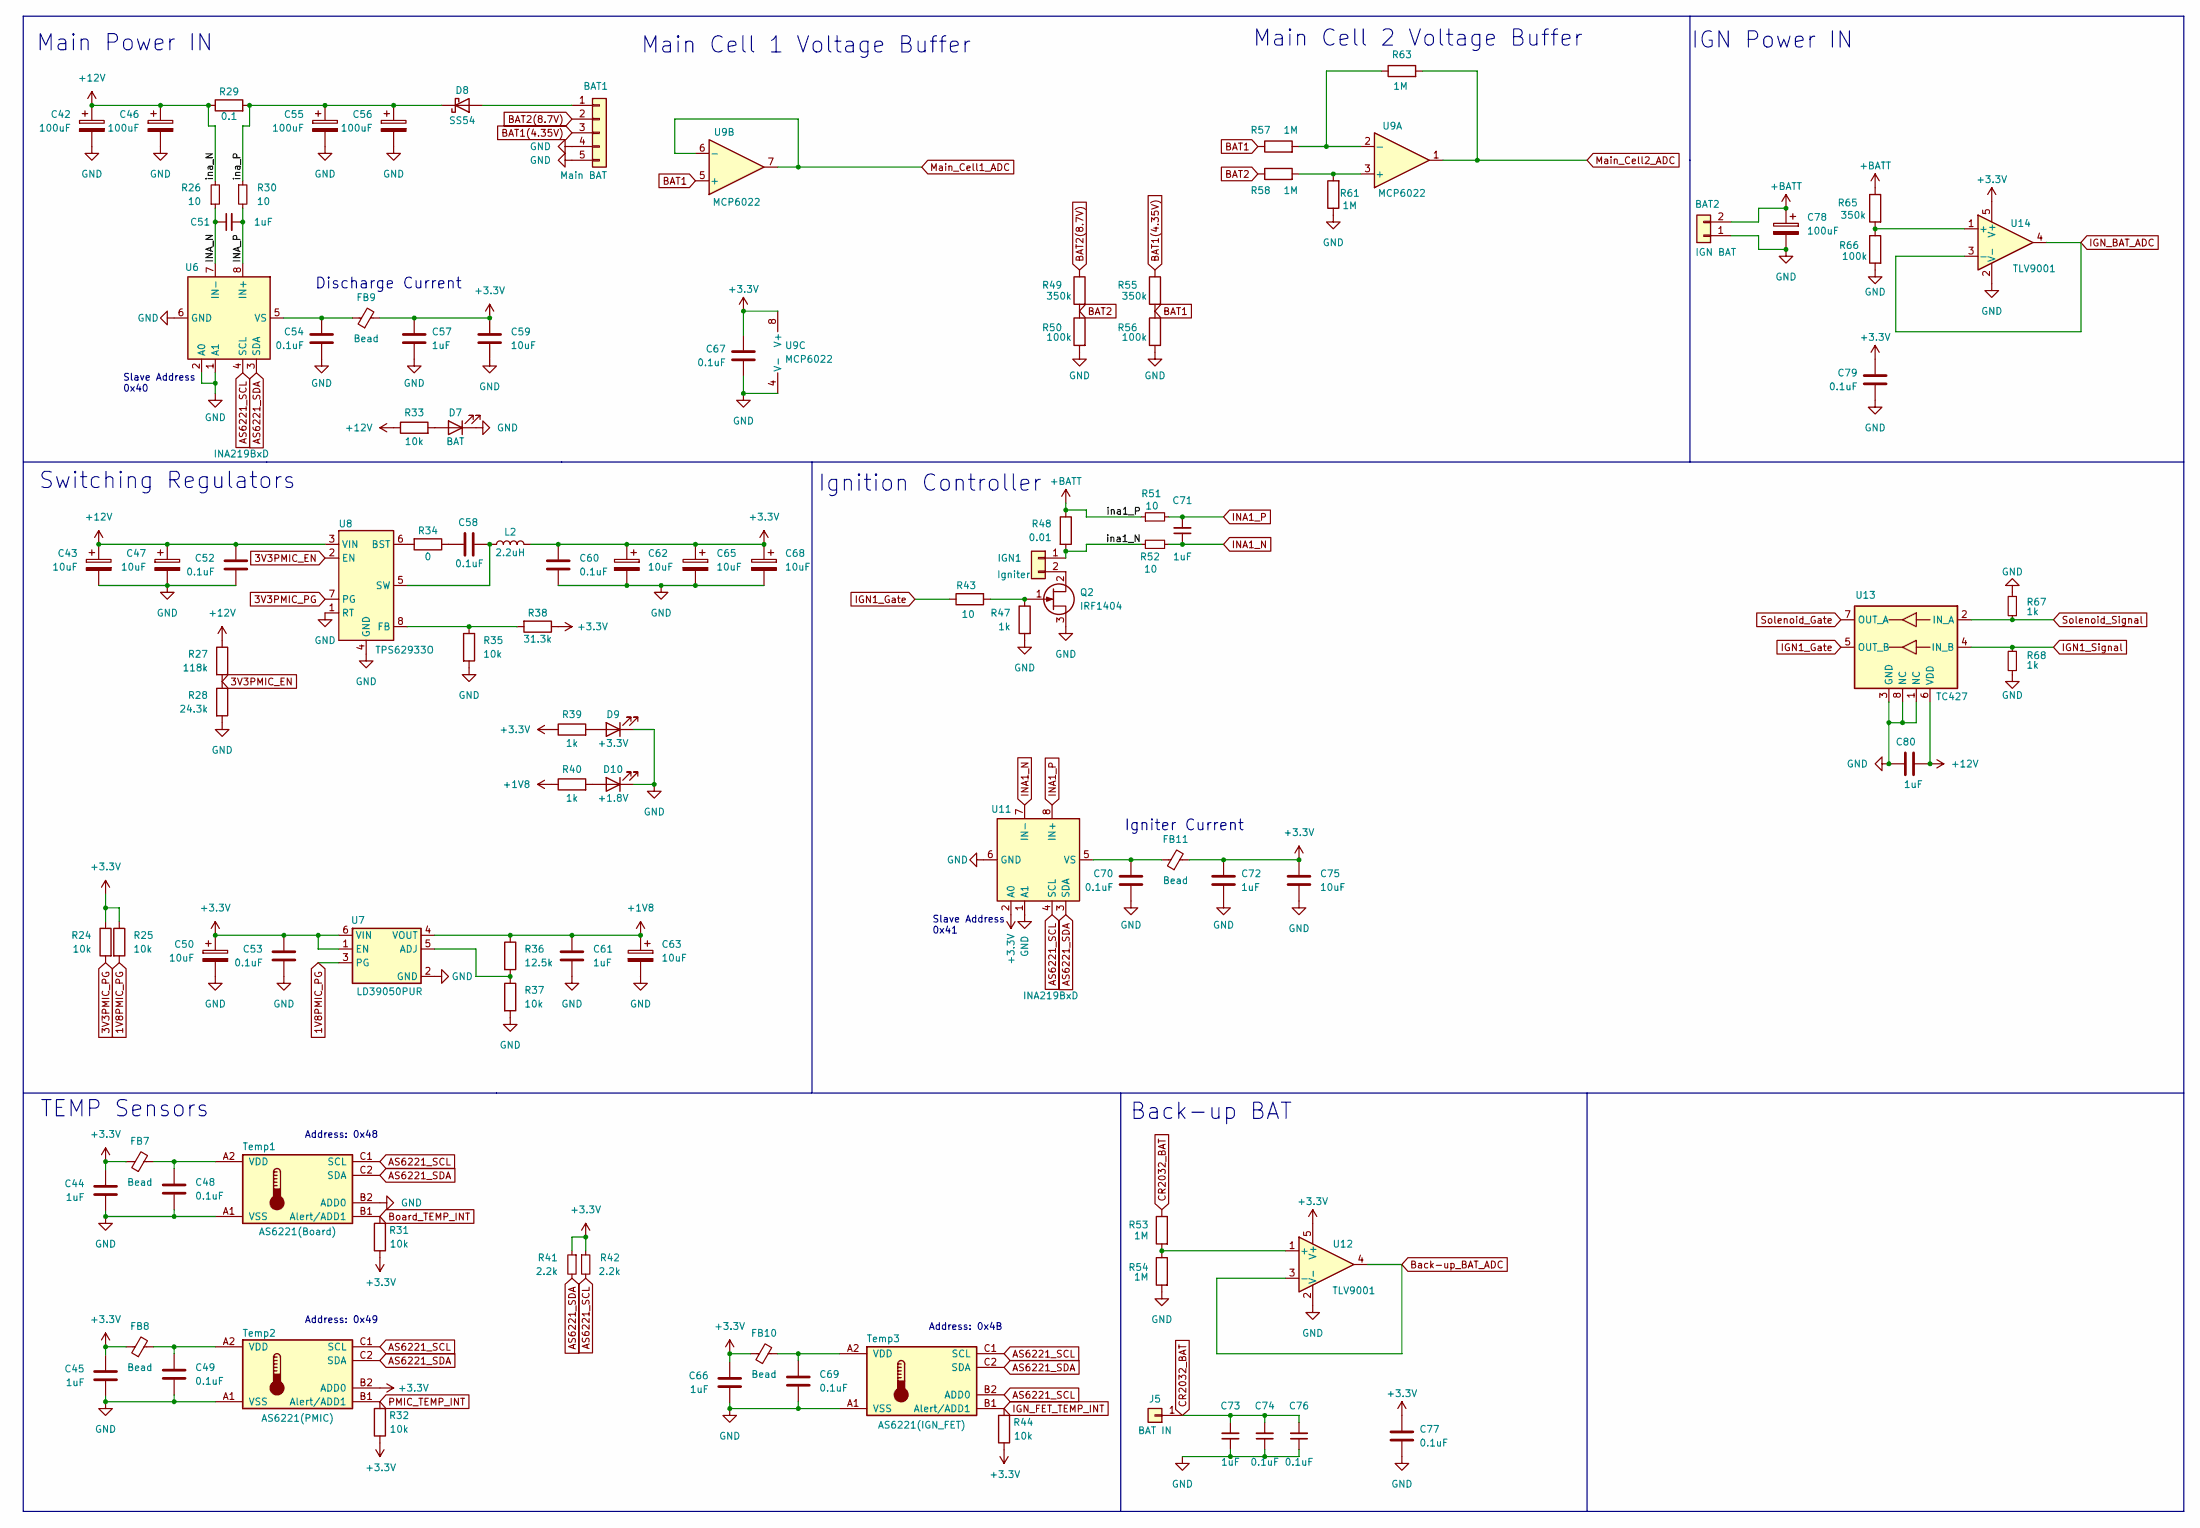
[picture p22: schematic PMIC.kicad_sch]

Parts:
BAT1: Main BAT; SAMTEC_T1M-05-F-SH-L
BAT2: IGN BAT; AMASS_XT30U-M_1x02_P5.0mm_Vertical
C42, C46, C55, C56, C78: 100uF; CP_EIA-7343-43_Kemet-X
C43, C47, C50, C59, C62, C63, C65, C68, C75: 10uF; C_0805_2012Metric
C44, C45, C51, C57, C61, C66, C71, C72, C73, C80: 1uF; C_0603_1608Metric
C48, C49, C52, C53, C54, C58, C60, C67, C69, C70, C74, C76, C77, C79: 0.1uF; C_0603_1608Metric
D7: BAT; LED_0805_2012Metric
D8: SS54; D_SMA
D9: +3.3V; LED_0805_2012Metric
D10: +1.8V; LED_0805_2012Metric
FB7, FB8, FB9, FB10, FB11: Bead; L_0603_1608Metric
IGN1: Igniter; JST_VH_B2P-VH_1x02_P3.96mm_Vertical
J5: BAT IN; PinHeader_1x01_P2.54mm_Vertical
L2: 2.2uH; L_Coilcraft_XAL6030-XXX
Q2: IRF1404; TO-263-2
R24, R25, R31, R32, R33, R35, R37, R44: 10k; R_0603_1608Metric
R26, R30, R43, R51, R52: 10; R_0603_1608Metric
R27: 118k; R_0603_1608Metric
R28: 24.3k; R_0603_1608Metric
R29: 0.1; R_2816_7142Metric
R34: 0; R_0603_1608Metric
R36: 12.5k; R_0603_1608Metric
R38: 31.3k; R_0603_1608Metric
R39, R40, R47, R67, R68: 1k; R_0603_1608Metric
R41, R42: 2.2k; R_0603_1608Metric
R48: 0.01; R_2816_7142Metric
R49, R55, R65: 350k; R_0603_1608Metric
R50, R56, R66: 100k; R_0603_1608Metric
R53, R54, R57, R58, R61, R63: 1M; R_0603_1608Metric
Temp1: AS6221(Board); WLCSP-6_1.4x1.0mm_P0.4mm
Temp2: AS6221(PMIC); WLCSP-6_1.4x1.0mm_P0.4mm
Temp3: AS6221(IGN_FET); WLCSP-6_1.4x1.0mm_P0.4mm
U6, U11: INA219BxD; SOIC-8_3.9x4.9mm_P1.27mm
U7: LD39050PUR; DFN-6-1EP_3x3mm_P0.95mm_EP1.7x2.6mm
U8: TPS62933O; SOT-583-8
U9: MCP6022; SOIC-8_3.9x4.9mm_P1.27mm
U12, U14: TLV9001; SOT-353_SC-70-5
U13: TC427; SOIC-8_3.9x4.9mm_P1.27mm

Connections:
1V8PMIC_PG: R25.2, U7.3 (PG); also elsewhere on the board
3V3PMIC_EN: R27.2, R28.1, U8.2 (EN)
3V3PMIC_PG: R24.2, U8.7 (PG); also elsewhere on the board
+1V8: C61.1, C63.1, R36.1, R40.1, U7.4 (VOUT); also elsewhere on the board
+3.3V: C44.2, C45.2, C50.1, C53.1, C57.1, C59.1, C60.1, C62.1, C65.1, C66.2, C67.2, C68.1, C72.1, C75.1, C77.2, C79.2, FB7.1, FB8.1, FB9.2, FB10.1, FB11.2, L2.2, R24.1, R25.1, R31.1, R32.1, R38.1, R39.1, R41.1, R42.1, R44.1, Temp2.B2 (ADD0), U7.1 (EN), U7.6 (VIN), U9.8 (V+), U11.2 (A0), U12.5 (V+), U14.5 (V+); also elsewhere on the board
+12V: C42.1, C43.1, C46.1, C47.1, C52.1, C80.2, R26.2, R27.1, R29.1, R33.1, U8.3 (VIN), U13.6 (VDD); also elsewhere on the board
+BATT: BAT2.2, C78.1, R48.1, R51.1, R65.1; also elsewhere on the board
/PMIC/INA_N: C51.1, R26.1, U6.7 (IN-)
/PMIC/INA_P: C51.2, R30.2, U6.8 (IN+)
/PMIC/ina1_N: IGN1.1, R48.2, R52.2
/PMIC/ina_P: C55.1, C56.1, D8.1 (K), R29.2, R30.1
AS6221_SCL: R42.2, Temp1.C1 (SCL), Temp2.C1 (SCL), Temp3.B2 (ADD0), Temp3.C1 (SCL), U6.4 (SCL), U11.4 (SCL); also elsewhere on the board
AS6221_SDA: R41.2, Temp1.C2 (SDA), Temp2.C2 (SDA), Temp3.C2 (SDA), U6.3 (SDA), U11.3 (SDA); also elsewhere on the board
BAT1: R55.2, R56.1, R57.1, U9.5 (+)
BAT1(4.35V): BAT1.3, R55.1
BAT2: R49.2, R50.1, R58.1
BAT2(8.7V): BAT1.2, R49.1
Back-up_BAT_ADC: U12.3 (-), U12.4; also elsewhere on the board
Board_TEMP_INT: R31.2, Temp1.B1 (Alert/ADD1); also elsewhere on the board
CR2032_BAT: C73.2, C74.2, C76.2, J5.1, R53.1; also elsewhere on the board
GND: BAT1.4, BAT1.5, BAT2.1, C42.2, C43.2, C44.1, C45.1, C46.2, C47.2, C48.2, C49.2, C50.2, C52.2, C53.2, C54.2, C55.2, C56.2, C57.2, C59.2, C60.2, C61.2, C62.2, C63.2, C65.2, C66.1, C67.1, C68.2, C69.2, C70.2, C72.2, C73.1, C74.1, C75.2, C76.1, C77.1, C78.2, C79.1, C80.1, D7.1 (K), D9.1 (K), D10.1 (K), Q2.3 (S), R28.2, R35.2, R37.2, R47.2, R50.2, R54.2, R56.2, R61.1, R66.2, R67.1, R68.1, Temp1.A1 (VSS), Temp1.B2 (ADD0), Temp2.A1 (VSS), Temp3.A1 (VSS), U6.1 (A1), U6.2 (A0), U6.6 (GND), U7.2 (GND), U7.7 (EP), U8.1 (RT), U8.4 (GND), U9.4 (V-), U11.1 (A1), U11.6 (GND), U12.2 (V-), U13.1 (NC), U13.3 (GND), U13.8 (NC), U14.2 (V-); also elsewhere on the board
IGN1_Gate: R43.1, U13.5 (OUT_B)
IGN1_Signal: R68.2, U13.4 (IN_B); also elsewhere on the board
IGN_BAT_ADC: U14.3 (-), U14.4; also elsewhere on the board
IGN_FET_TEMP_INT: R44.2, Temp3.B1 (Alert/ADD1); also elsewhere on the board
INA1_N: C71.1, R52.1, U11.7 (IN-)
INA1_P: C71.2, R51.2, U11.8 (IN+)
Main_Cell1_ADC: U9.6 (-), U9.7; also elsewhere on the board
Main_Cell2_ADC: R63.2, U9.1; also elsewhere on the board
unnamed: BAT1.1, D8.2 (A)
unnamed: C58.1, R34.1
unnamed: D7.2 (A), R33.2
unnamed: D9.2 (A), R39.2
unnamed: D10.2 (A), R40.2
unnamed: IGN1.2, Q2.2 (D)
unnamed: Q2.1 (G), R43.2, R47.1
unnamed: C48.1, FB7.2, Temp1.A2 (VDD)
unnamed: C49.1, FB8.2, Temp2.A2 (VDD)
unnamed: C69.1, FB10.2, Temp3.A2 (VDD)
unnamed: C54.1, FB9.1, U6.5 (VS)
unnamed: R36.2, R37.1, U7.5 (ADJ)
unnamed: R34.2, U8.6 (BST)
unnamed: R35.1, R38.2, U8.8 (FB)
unnamed: C58.2, L2.1, U8.5 (SW)
unnamed: R58.2, R61.2, U9.3 (+)
unnamed: R57.2, R63.1, U9.2 (-)
unnamed: C70.1, FB11.1, U11.5 (VS)
unnamed: R53.2, R54.1, U12.1 (+)
unnamed: R65.2, R66.1, U14.1 (+)
PMIC_TEMP_INT: R32.2, Temp2.B1 (Alert/ADD1); also elsewhere on the board
Solenoid_Gate: U13.7 (OUT_A); also elsewhere on the board
Solenoid_Signal: R67.2, U13.2 (IN_A); also elsewhere on the board

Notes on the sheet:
Address: 0x48
Switching Regulators
TEMP Sensors
Back-up BAT
Address: 0x4B
Main Power IN
Slave Address 0x41
Address: 0x49
Slave Address 0x40
Main Cell 2 Voltage Buffer
Igniter Current
Discharge Current
IGN Power IN
Main Cell 1 Voltage Buffer
Ignition Controller

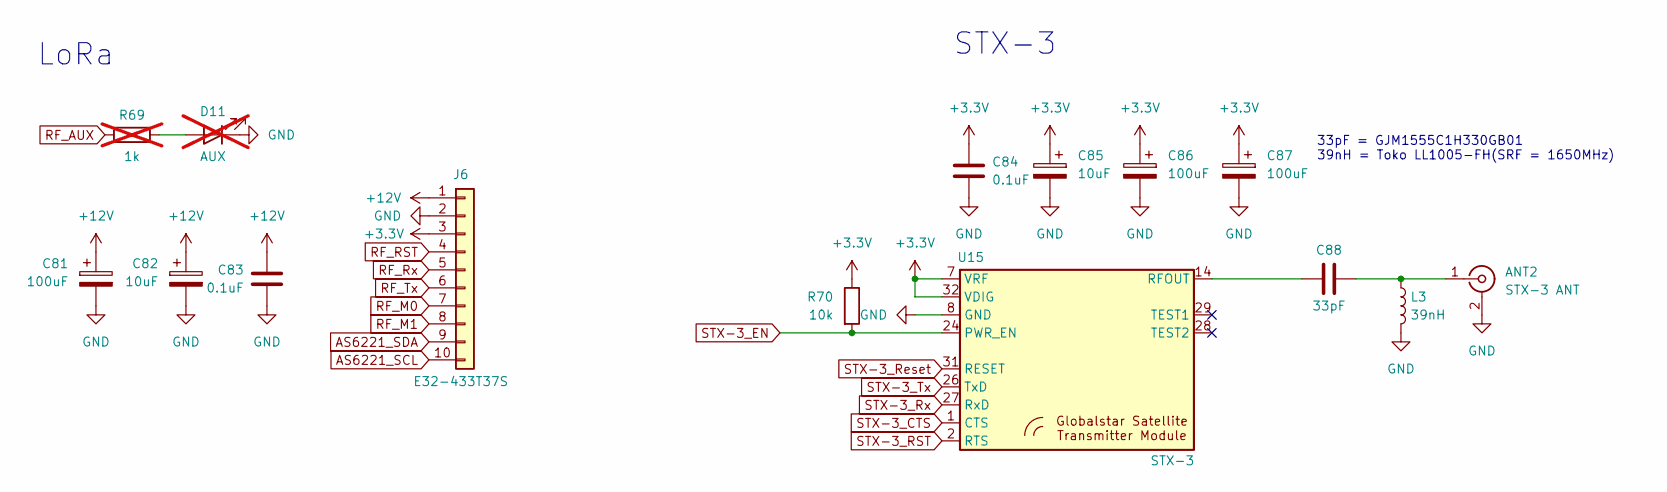
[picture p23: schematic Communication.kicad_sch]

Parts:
ANT2: STX-3 ANT; MMCX_Molex_73415-1471_Vertical
C81, C86, C87: 100uF; CP_EIA-7343-43_Kemet-X
C82, C85: 10uF; C_0805_2012Metric
C83, C84: 0.1uF; C_0603_1608Metric
C88: 33pF; C_0402_1005Metric
D11: AUX; LED_0805_2012Metric; not fitted
J6: E32-433T37S; SAMTEC_T1M-10-F-SH-L-K
L3: 39nH; L_0402_1005Metric
R69: 1k; R_0603_1608Metric; not fitted
R70: 10k; R_0603_1608Metric
U15: STX-3

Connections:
+3.3V: C84.1, C85.1, C86.1, C87.1, J6.3, R70.1, U15.7 (VRF), U15.32 (VDIG); also elsewhere on the board
+12V: C81.1, C82.1, C83.1, J6.1; also elsewhere on the board
AS6221_SCL: J6.10; also elsewhere on the board
AS6221_SDA: J6.9; also elsewhere on the board
GND: ANT2.2 (Ext), C81.2, C82.2, C83.2, C84.2, C85.2, C86.2, C87.2, D11.1 (K), J6.2, L3.2, U15.8 (GND), U15.9 (GND), U15.10 (GND), U15.11 (GND), U15.12 (GND), U15.13 (GND), U15.15 (GND), U15.16 (GND), U15.17 (GND), U15.18 (GND), U15.19 (GND), U15.20 (GND); also elsewhere on the board
unnamed: ANT2.1 (In), C88.2, L3.1
unnamed: D11.2 (A), R69.2
unnamed: C88.1, U15.14 (RFOUT)
RF_M0: J6.7; also elsewhere on the board
RF_M1: J6.8; also elsewhere on the board
RF_RST: J6.4; also elsewhere on the board
RF_Rx: J6.5; also elsewhere on the board
RF_Tx: J6.6; also elsewhere on the board
STX-3_CTS: U15.1 (CTS); also elsewhere on the board
STX-3_EN: R70.2, U15.24 (PWR_EN); also elsewhere on the board
STX-3_RST: U15.2 (RTS); also elsewhere on the board
STX-3_Reset: U15.31 (RESET); also elsewhere on the board
STX-3_Rx: U15.27 (RxD); also elsewhere on the board
STX-3_Tx: U15.26 (TxD); also elsewhere on the board

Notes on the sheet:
33pF = GJM1555C1H330GB01 39nH = Toko LL1005-FH(SRF = 1650MHz)
STX-3
LoRa

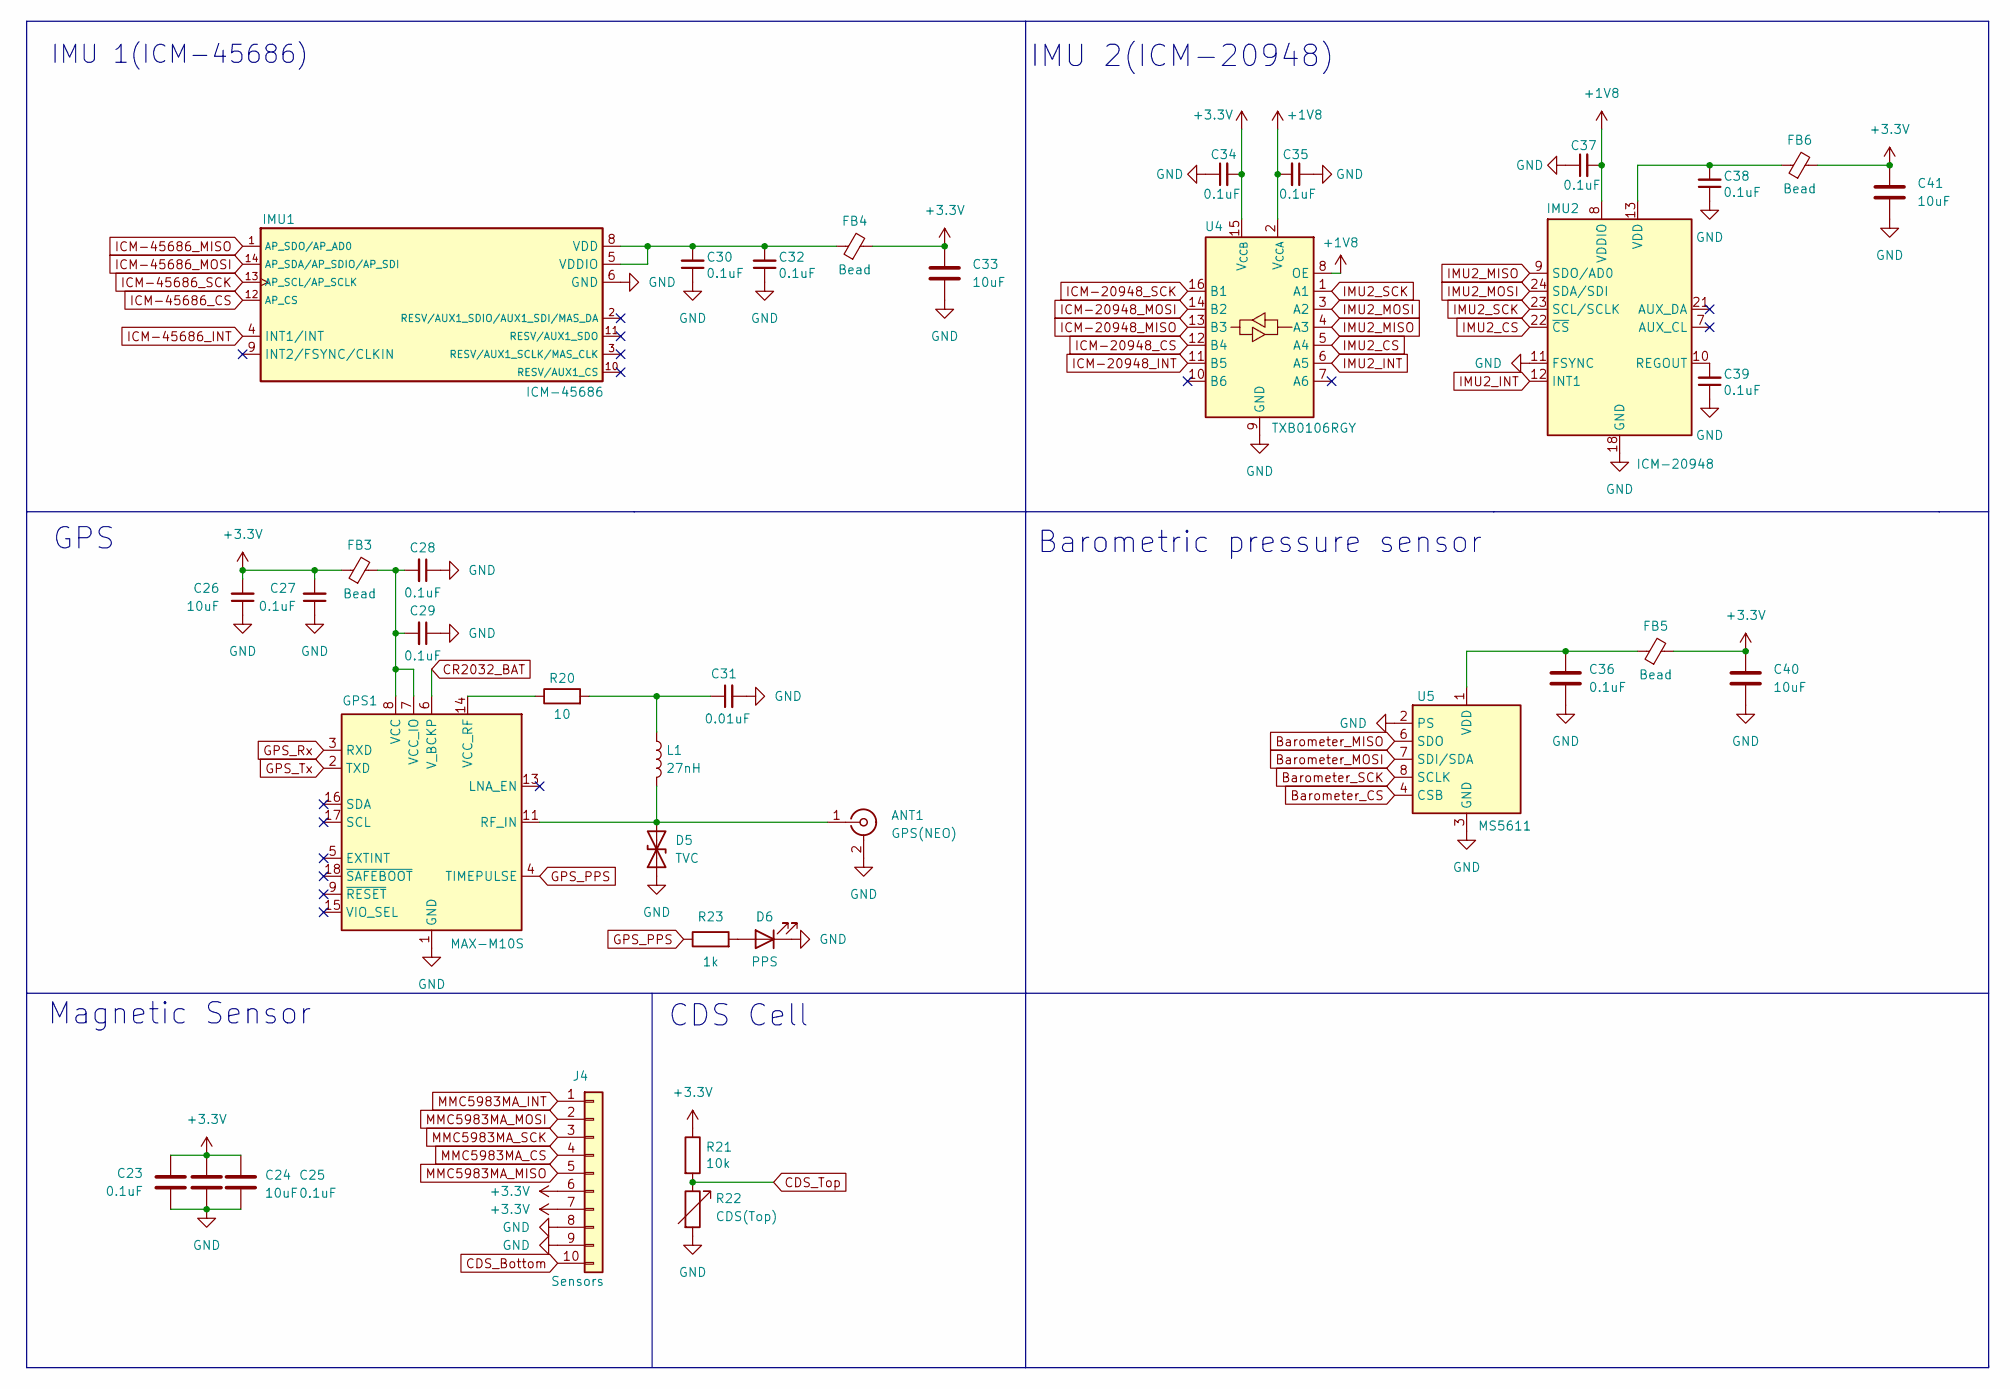
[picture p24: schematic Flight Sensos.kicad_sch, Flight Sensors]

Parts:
ANT1: GPS(NEO); SMA_Amphenol_132134-11_Vertical
C23, C25, C27, C28, C29, C30, C32, C34, C35, C36, C37, C38, C39: 0.1uF; C_0603_1608Metric
C24, C26, C33, C40, C41: 10uF; C_0805_2012Metric
C31: 0.01uF; C_0603_1608Metric
D5: TVC; D_0402_1005Metric
D6: PPS; LED_0805_2012Metric
FB3, FB4, FB5, FB6: Bead; L_0603_1608Metric
GPS1: MAX-M10S; ublox_MAX
IMU1: ICM-45686; IC_ICM-45686
IMU2: ICM-20948; InvenSense_QFN-24_3x3mm_P0.4mm
J4: Sensors; SAMTEC_T1M-10-F-SH-L-K
L1: 27nH; L_0805_2012Metric
R20: 10; R_0603_1608Metric
R21: 10k; R_0603_1608Metric
R22: CDS(Top); R_LDR_5.0x4.1mm_P3mm_Vertical
R23: 1k; R_0603_1608Metric
U4: TXB0106RGY; Texas_RGY_R-PVQFN-N16_EP2.05x2.55mm
U5: MS5611; LGA-8_3x5mm_P1.25mm

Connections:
+1V8: C35.2, C37.2, IMU2.8 (VDDIO), U4.2 (V_{CCA}), U4.8 (OE); also elsewhere on the board
+3.3V: C23.1, C24.1, C25.1, C26.2, C27.2, C33.1, C34.2, C40.1, C41.1, FB3.1, FB4.2, FB5.2, FB6.2, J4.6, J4.7, R21.1, U4.15 (V_{CCB}); also elsewhere on the board
Barometer_CS: U5.4 (CSB), U5.5 (CSB); also elsewhere on the board
Barometer_MISO: U5.6 (SDO); also elsewhere on the board
Barometer_MOSI: U5.7 (SDI/SDA); also elsewhere on the board
Barometer_SCK: U5.8 (SCLK); also elsewhere on the board
CDS_Bottom: J4.10; also elsewhere on the board
CDS_Top: R21.2, R22.1; also elsewhere on the board
CR2032_BAT: GPS1.6 (V_BCKP); also elsewhere on the board
GND: ANT1.2 (Ext), C23.2, C24.2, C25.2, C26.1, C27.1, C28.1, C29.1, C30.1, C31.2, C32.1, C33.2, C34.1, C35.1, C36.2, C37.1, C38.1, C39.1, C40.2, C41.2, D5.1 (A1), D6.1 (K), GPS1.1 (GND), GPS1.10 (GND), GPS1.12 (GND), IMU1.6 (GND), IMU1.7 (RESV), IMU2.11 (FSYNC), IMU2.18 (GND), IMU2.20 (GND), J4.8, J4.9, R22.2, U4.9 (GND), U4.17 (GND), U5.2 (PS), U5.3 (GND); also elsewhere on the board
GPS_PPS: GPS1.4 (TIMEPULSE), R23.1
GPS_Rx: GPS1.3 (RXD); also elsewhere on the board
GPS_Tx: GPS1.2 (TXD); also elsewhere on the board
ICM-20948_CS: U4.12 (B4); also elsewhere on the board
ICM-20948_INT: U4.11 (B5); also elsewhere on the board
ICM-20948_MISO: U4.13 (B3); also elsewhere on the board
ICM-20948_MOSI: U4.14 (B2); also elsewhere on the board
ICM-20948_SCK: U4.16 (B1); also elsewhere on the board
ICM-45686_CS: IMU1.12 (AP_CS); also elsewhere on the board
ICM-45686_INT: IMU1.4 (INT1/INT); also elsewhere on the board
ICM-45686_MISO: IMU1.1 (AP_SDO/AP_AD0); also elsewhere on the board
ICM-45686_MOSI: IMU1.14 (AP_SDA/AP_SDIO/AP_SDI); also elsewhere on the board
ICM-45686_SCK: IMU1.13 (AP_SCL/AP_SCLK); also elsewhere on the board
IMU2_CS: IMU2.22 (~CS), U4.5 (A4)
IMU2_INT: IMU2.12 (INT1), U4.6 (A5)
IMU2_MISO: IMU2.9 (SDO/AD0), U4.4 (A3)
IMU2_MOSI: IMU2.24 (SDA/SDI), U4.3 (A2)
IMU2_SCK: IMU2.23 (SCL/SCLK), U4.1 (A1)
MMC5983MA_CS: J4.4; also elsewhere on the board
MMC5983MA_INT: J4.1; also elsewhere on the board
MMC5983MA_MISO: J4.5; also elsewhere on the board
MMC5983MA_MOSI: J4.2; also elsewhere on the board
MMC5983MA_SCK: J4.3; also elsewhere on the board
unnamed: ANT1.1 (In), D5.2 (A2), GPS1.11 (RF_IN), L1.2
unnamed: C31.1, L1.1, R20.2
unnamed: D6.2 (A), R23.2
unnamed: C28.2, C29.2, FB3.2, GPS1.7 (VCC_IO), GPS1.8 (VCC)
unnamed: GPS1.14 (VCC_RF), R20.1
unnamed: C30.2, C32.2, FB4.1, IMU1.5 (VDDIO), IMU1.8 (VDD)
unnamed: C39.2, IMU2.10 (REGOUT)
unnamed: C38.2, FB6.1, IMU2.13 (VDD)
unnamed: C36.1, FB5.1, U5.1 (VDD)

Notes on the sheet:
GPS
IMU 2(ICM-20948)
IMU 1(ICM-45686)
CDS Cell
Magnetic Sensor
Barometric pressure sensor

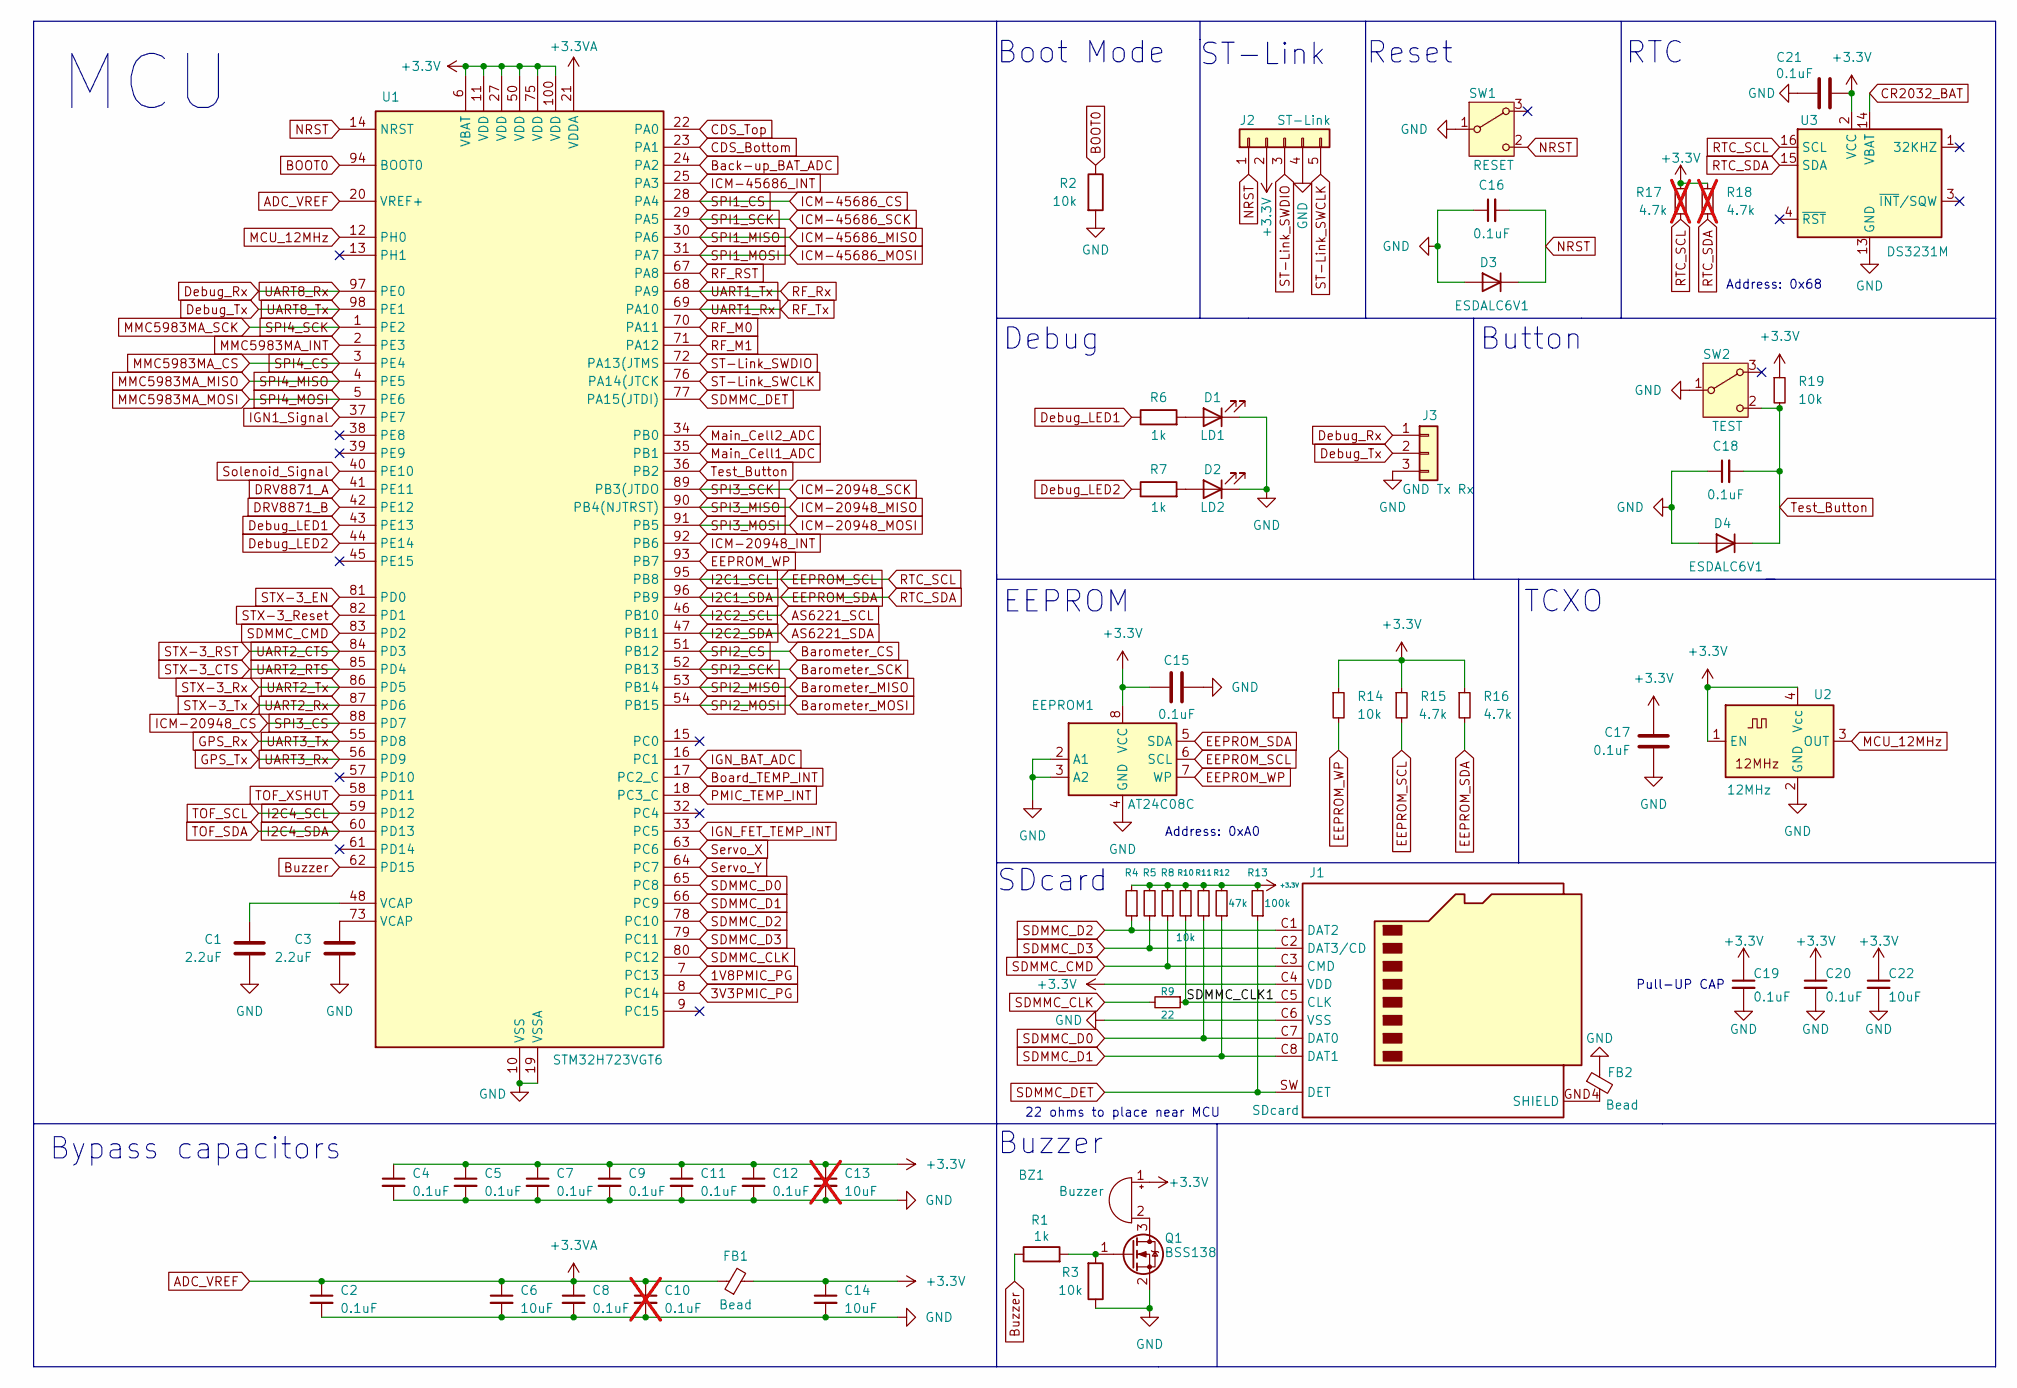
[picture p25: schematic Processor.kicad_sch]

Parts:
BZ1: Buzzer; XDCR_SMTB-0827-TW-R
C1, C3: 2.2uF; C_0603_1608Metric
C2, C4, C5, C7, C8, C9, C11, C12, C15, C16, C17, C18, C19, C20, C21: 0.1uF; C_0603_1608Metric
C6, C14, C22: 10uF; C_0805_2012Metric
C10: 0.1uF; C_0603_1608Metric; not fitted
C13: 10uF; C_0805_2012Metric; not fitted
D1: LD1; LED_0805_2012Metric
D2: LD2; LED_0805_2012Metric
D3, D4: ESDALC6V1; D_SOD-882D
EEPROM1: AT24C08C; SOIC-8_3.9x4.9mm_P1.27mm
FB1, FB2: Bead; L_0603_1608Metric
J1: SDcard; JAE_ST1W008S4TR2000
J2: ST-Link; PinHeader_1x05_P2.54mm_Vertical
J3: GND Tx Rx; PinHeader_1x03_P2.54mm_Vertical
Q1: BSS138; SOT-23
R1, R6, R7: 1k; R_0603_1608Metric
R2, R3, R10, R14, R19: 10k; R_0603_1608Metric
R4, R5, R8, R11, R12: 47k; R_0603_1608Metric
R9: 22; R_0402_1005Metric
R13: 100k; R_0603_1608Metric
R15, R16: 4.7k; R_0603_1608Metric
R17, R18: 4.7k; R_0603_1608Metric; not fitted
SW1: RESET; TLSMDT3C020GLFS
SW2: TEST; TLSMDT3C020GLFS
U1: STM32H723VGT6; LQFP-100_14x14mm_P0.5mm
U2: 12MHz; ECS-TXO-2016
U3: DS3231M; SOIC-16W_7.5x10.3mm_P1.27mm

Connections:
1V8PMIC_PG: U1.7 (PC13); also elsewhere on the board
3V3PMIC_PG: U1.8 (PC14); also elsewhere on the board
+3.3V: BZ1.1 (-), C4.1, C5.1, C7.1, C9.1, C11.1, C12.1, C13.1, C14.1, C15.1, C17.1, C19.1, C20.1, C21.2, C22.1, EEPROM1.8 (VCC), FB1.2, J1.C4 (VDD), J2.2, R4.2, R5.2, R8.2, R10.2, R11.2, R12.2, R13.2, R14.1, R15.1, R16.1, R17.1, R18.1, R19.1, U1.6 (VBAT), U1.11 (VDD), U1.27 (VDD), U1.50 (VDD), U1.75 (VDD), U1.100 (VDD), U2.1 (EN), U2.4 (Vcc), U3.2 (VCC); also elsewhere on the board
/Processor/SDMMC_CLK1: J1.C5 (CLK), R9.1, R10.1
ADC_VREF: C2.1, C6.1, C8.1, C10.1, FB1.1, U1.20 (VREF+), U1.21 (VDDA)
AS6221_SCL: U1.46 (PB10); also elsewhere on the board
AS6221_SDA: U1.47 (PB11); also elsewhere on the board
BOOT0: R2.1, U1.94 (BOOT0)
Back-up_BAT_ADC: U1.24 (PA2); also elsewhere on the board
Barometer_CS: U1.51 (PB12); also elsewhere on the board
Barometer_MISO: U1.53 (PB14); also elsewhere on the board
Barometer_MOSI: U1.54 (PB15); also elsewhere on the board
Barometer_SCK: U1.52 (PB13); also elsewhere on the board
Board_TEMP_INT: U1.17 (PC2_C); also elsewhere on the board
Buzzer: R1.1, U1.62 (PD15)
CDS_Bottom: U1.23 (PA1); also elsewhere on the board
CDS_Top: U1.22 (PA0); also elsewhere on the board
CR2032_BAT: U3.14 (VBAT); also elsewhere on the board
DRV8871_A: U1.41 (PE11); also elsewhere on the board
DRV8871_B: U1.42 (PE12); also elsewhere on the board
Debug_LED1: R6.1, U1.43 (PE13)
Debug_LED2: R7.1, U1.44 (PE14)
Debug_Rx: J3.1, U1.97 (PE0)
Debug_Tx: J3.2, U1.98 (PE1)
EEPROM_SCL: EEPROM1.6 (SCL), R15.2, R17.2, U1.95 (PB8), U3.16 (SCL)
EEPROM_SDA: EEPROM1.5 (SDA), R16.2, R18.2, U1.96 (PB9), U3.15 (SDA)
EEPROM_WP: EEPROM1.7 (WP), R14.2, U1.93 (PB7)
GND: C1.2, C2.2, C3.2, C4.2, C5.2, C6.2, C7.2, C8.2, C9.2, C10.2, C11.2, C12.2, C13.2, C14.2, C15.2, C16.1, C17.2, C18.1, C19.2, C20.2, C21.1, C22.2, D1.1 (K), D2.1 (K), D3.2 (A), D4.2 (A), EEPROM1.2 (A1), EEPROM1.3 (A2), EEPROM1.4 (GND), FB2.1, J1.C6 (VSS), J2.4, J3.3, Q1.2 (S), R2.2, R3.1, SW1.1 (B), SW2.1 (B), U1.10 (VSS), U1.19 (VSSA), U1.26 (VSS), U1.49 (VSS), U1.74 (VSS), U1.99 (VSS), U2.2 (GND), U3.5 (GND), U3.6 (GND), U3.7 (GND), U3.8 (GND), U3.9 (GND), U3.10 (GND), U3.11 (GND), U3.12 (GND), U3.13 (GND); also elsewhere on the board
GPS_Rx: U1.55 (PD8); also elsewhere on the board
GPS_Tx: U1.56 (PD9); also elsewhere on the board
I2C4_SCL: U1.59 (PD12); also elsewhere on the board
I2C4_SDA: U1.60 (PD13); also elsewhere on the board
ICM-20948_CS: U1.88 (PD7); also elsewhere on the board
ICM-20948_INT: U1.92 (PB6); also elsewhere on the board
ICM-20948_MISO: U1.90 (PB4(NJTRST)); also elsewhere on the board
ICM-20948_MOSI: U1.91 (PB5); also elsewhere on the board
ICM-20948_SCK: U1.89 (PB3(JTDO); also elsewhere on the board
ICM-45686_CS: U1.28 (PA4); also elsewhere on the board
ICM-45686_INT: U1.25 (PA3); also elsewhere on the board
ICM-45686_MISO: U1.30 (PA6); also elsewhere on the board
ICM-45686_MOSI: U1.31 (PA7); also elsewhere on the board
ICM-45686_SCK: U1.29 (PA5); also elsewhere on the board
IGN1_Signal: U1.37 (PE7); also elsewhere on the board
IGN_BAT_ADC: U1.16 (PC1); also elsewhere on the board
IGN_FET_TEMP_INT: U1.33 (PC5); also elsewhere on the board
MCU_12MHz: U1.12 (PH0), U2.3 (OUT)
MMC5983MA_CS: U1.3 (PE4); also elsewhere on the board
MMC5983MA_INT: U1.2 (PE3); also elsewhere on the board
MMC5983MA_MISO: U1.4 (PE5); also elsewhere on the board
MMC5983MA_MOSI: U1.5 (PE6); also elsewhere on the board
MMC5983MA_SCK: U1.1 (PE2); also elsewhere on the board
Main_Cell1_ADC: U1.35 (PB1); also elsewhere on the board
Main_Cell2_ADC: U1.34 (PB0); also elsewhere on the board
NRST: C16.2, D3.1 (K), J2.1, SW1.2 (C), U1.14 (NRST)
unnamed: BZ1.2 (+), Q1.3 (D)
unnamed: C1.1, U1.48 (VCAP)
unnamed: C3.1, U1.73 (VCAP)
unnamed: D1.2 (A), R6.2
unnamed: D2.2 (A), R7.2
unnamed: FB2.2, J1.GND4 (SHIELD)
unnamed: Q1.1 (G), R1.2, R3.2
PMIC_TEMP_INT: U1.18 (PC3_C); also elsewhere on the board
RF_M0: U1.70 (PA11); also elsewhere on the board
RF_M1: U1.71 (PA12); also elsewhere on the board
RF_RST: U1.67 (PA8); also elsewhere on the board
RF_Rx: U1.68 (PA9); also elsewhere on the board
RF_Tx: U1.69 (PA10); also elsewhere on the board
SDMMC_CLK: R9.2, U1.80 (PC12)
SDMMC_CMD: J1.C3 (CMD), R8.1, U1.83 (PD2)
SDMMC_D0: J1.C7 (DAT0), R11.1, U1.65 (PC8)
SDMMC_D1: J1.C8 (DAT1), R12.1, U1.66 (PC9)
SDMMC_D2: J1.C1 (DAT2), R4.1, U1.78 (PC10)
SDMMC_D3: J1.C2 (DAT3/CD), R5.1, U1.79 (PC11)
SDMMC_DET: J1.SW (DET), R13.1, U1.77 (PA15(JTDI))
ST-Link_SWCLK: J2.5, U1.76 (PA14(JTCK)
ST-Link_SWDIO: J2.3, U1.72 (PA13(JTMS)
STX-3_CTS: U1.85 (PD4); also elsewhere on the board
STX-3_EN: U1.81 (PD0); also elsewhere on the board
STX-3_RST: U1.84 (PD3); also elsewhere on the board
STX-3_Reset: U1.82 (PD1); also elsewhere on the board
STX-3_Rx: U1.86 (PD5); also elsewhere on the board
STX-3_Tx: U1.87 (PD6); also elsewhere on the board
Servo_X: U1.63 (PC6); also elsewhere on the board
Servo_Y: U1.64 (PC7); also elsewhere on the board
Solenoid_Signal: U1.40 (PE10); also elsewhere on the board
TOF_XSHUT: U1.58 (PD11); also elsewhere on the board
Test_Button: C18.2, D4.1 (K), R19.2, SW2.2 (C), U1.36 (PB2)

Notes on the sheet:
Address: 0x68
Bypass capacitors
Address: 0xA0
EEPROM
22 ohms to place near MCU
ST-Link
Buzzer
Boot Mode
RTC
Debug
Button
SDcard
Pull-UP CAP
Reset
MCU
TCXO

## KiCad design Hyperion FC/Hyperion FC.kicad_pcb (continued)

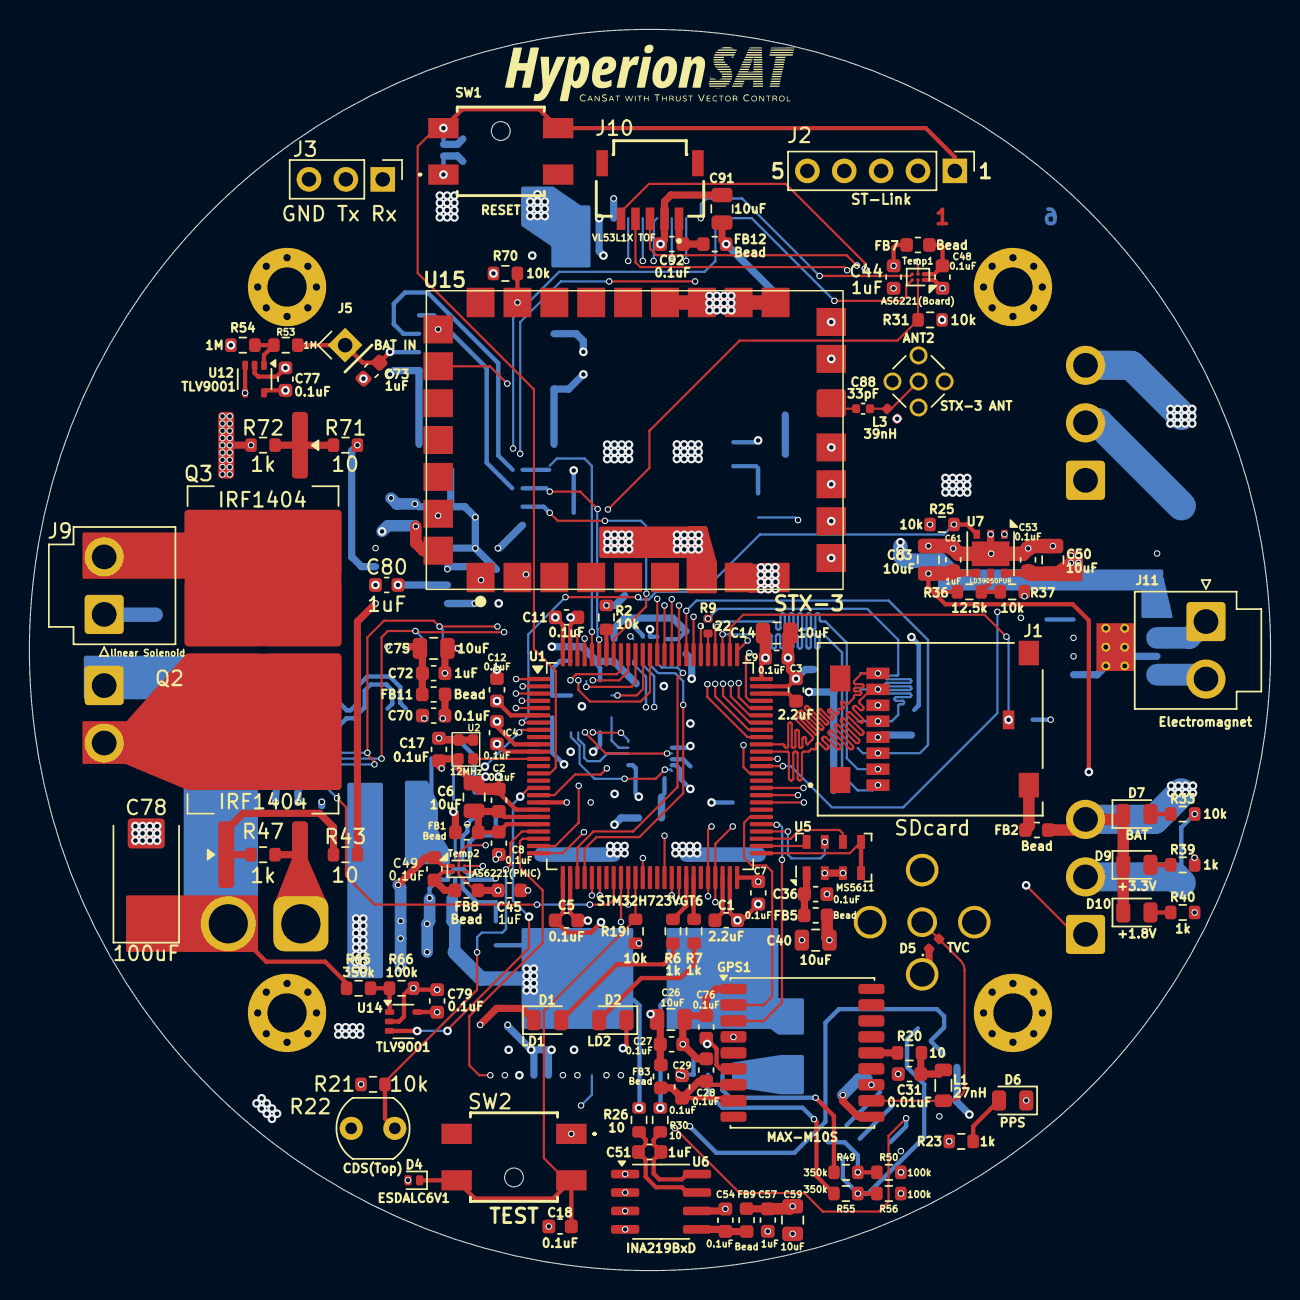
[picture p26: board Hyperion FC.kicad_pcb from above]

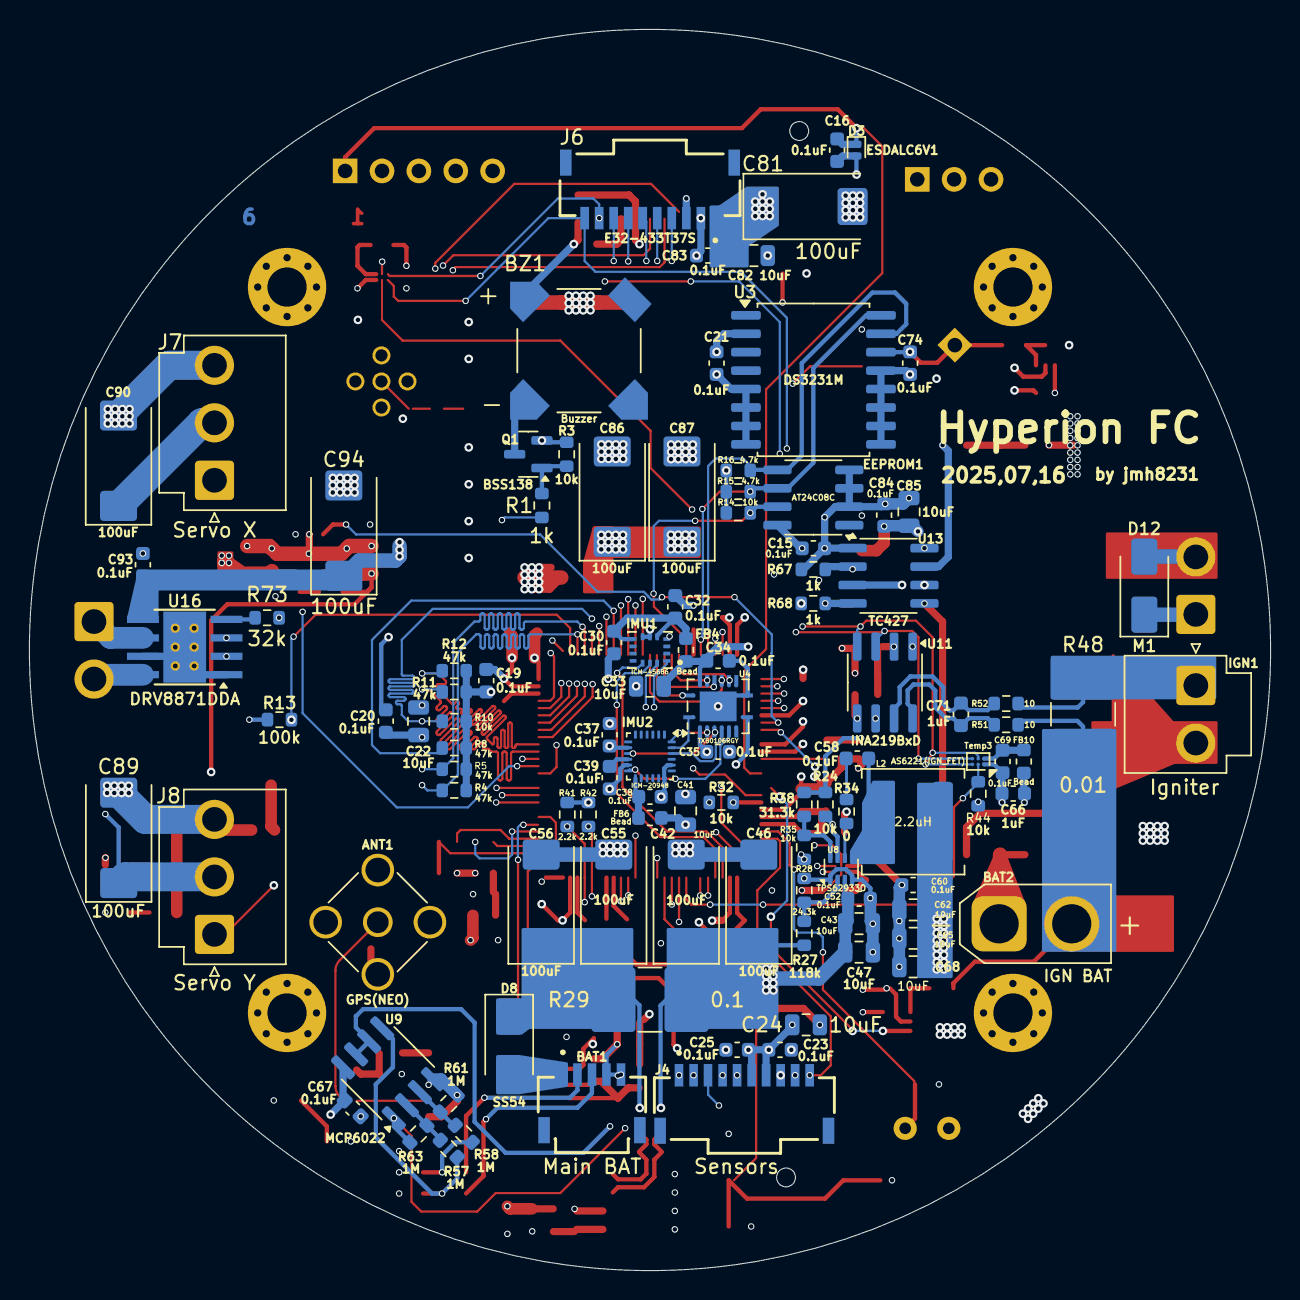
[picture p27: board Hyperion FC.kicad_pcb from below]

Board: 6 copper layers, 85.5 x 85.5 mm, 229 parts (107 on the bottom side), 146 nets.

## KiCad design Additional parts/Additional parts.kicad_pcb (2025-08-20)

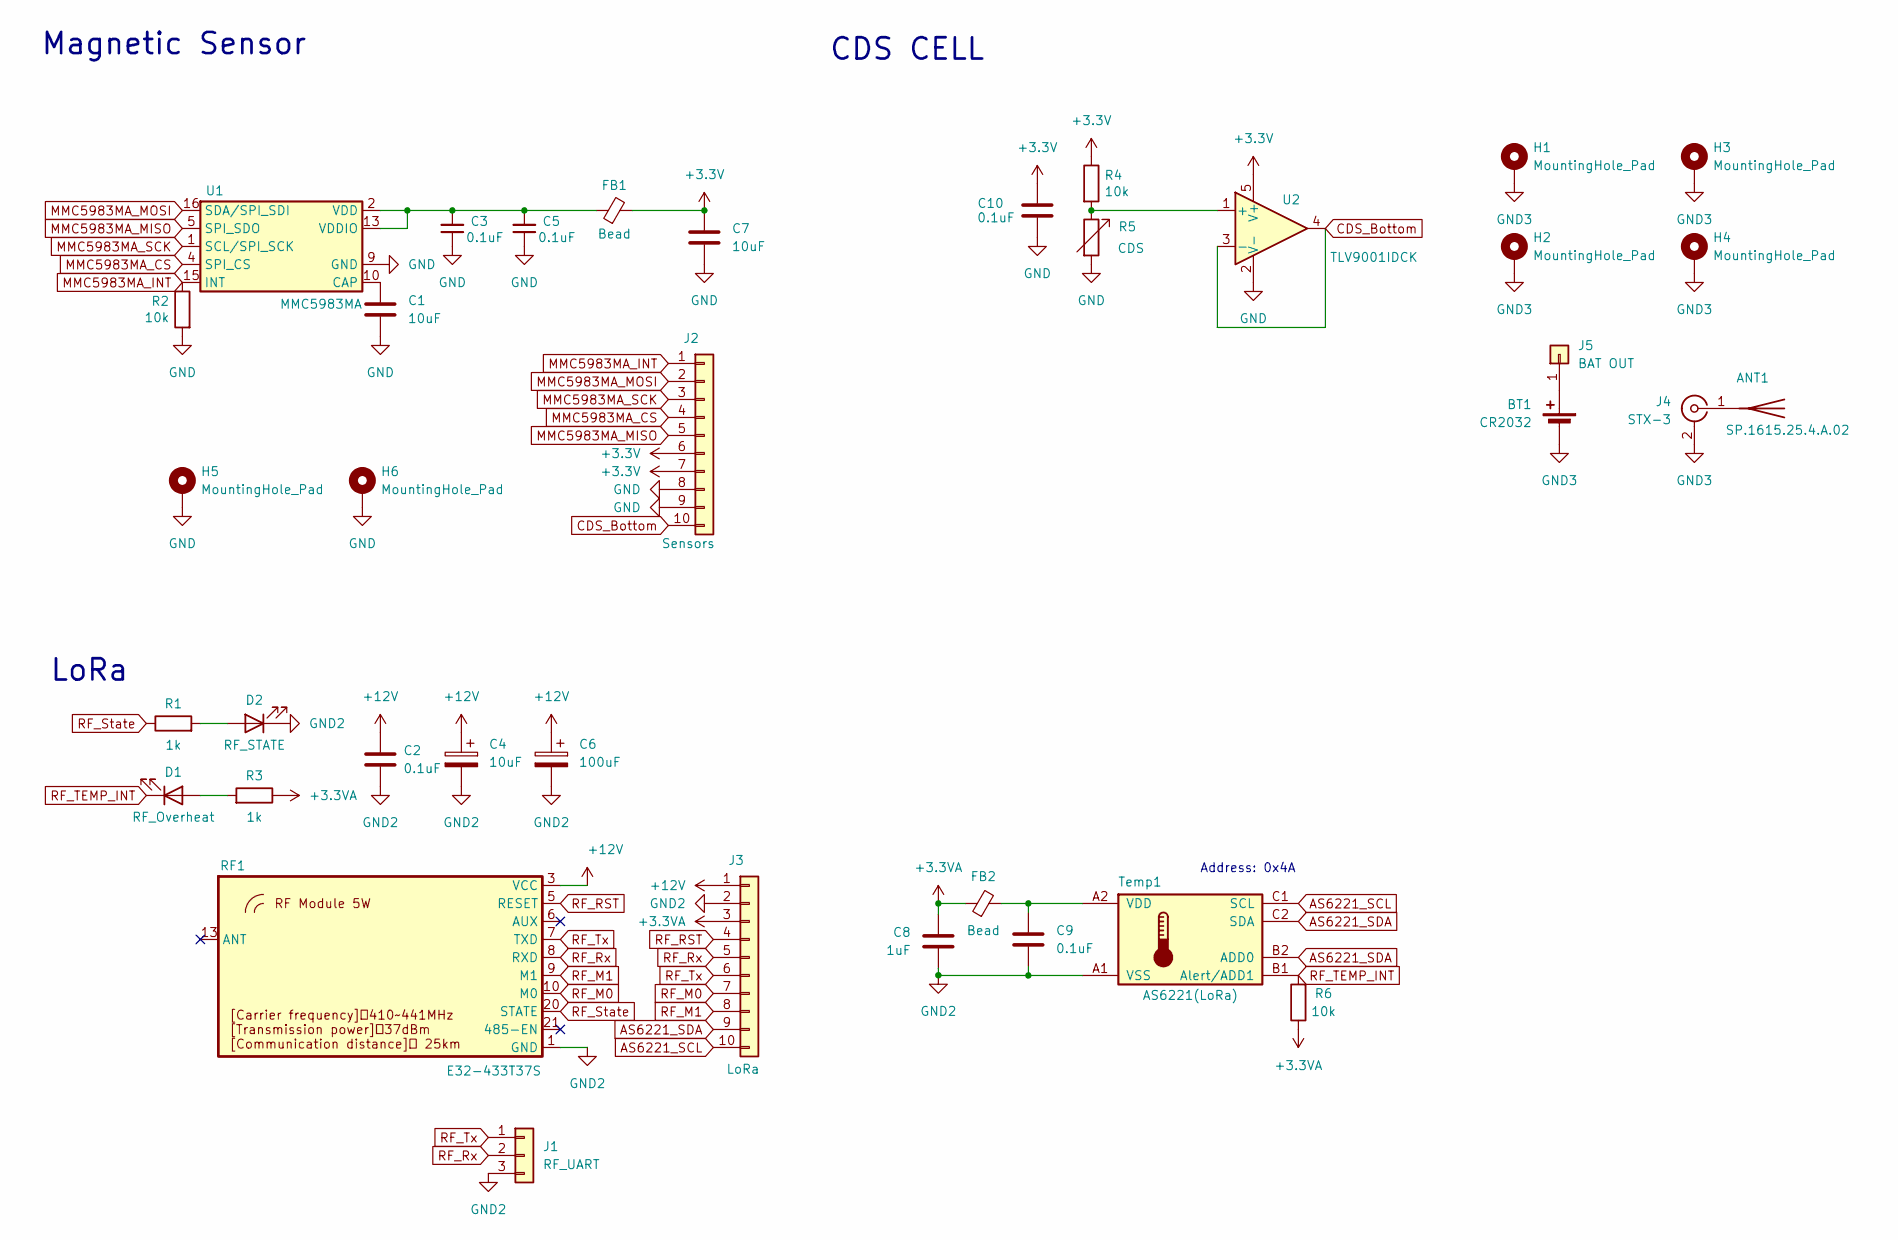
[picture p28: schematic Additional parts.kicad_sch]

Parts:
ANT1: SP.1615.25.4.A.02
BT1: CR2032; BAT-HLD-001
C1, C4, C7: 10uF; C_0805_2012Metric
C2, C3, C5, C9, C10: 0.1uF; C_0603_1608Metric
C6: 100uF; CP_EIA-7343-43_Kemet-X
C8: 1uF; C_0603_1608Metric
D1: RF_Overheat; LED_0805_2012Metric
D2: RF_STATE; LED_0805_2012Metric
FB1, FB2: Bead; L_0603_1608Metric
H1, H2, H3, H4, H5, H6: MountingHole_Pad; MountingHole_2.7mm_M2.5_Pad_Via
J1: RF_UART; PinHeader_1x03_P2.54mm_Vertical
J2: Sensors; SAMTEC_T1M-10-F-SH-L-K
J3: LoRa; SAMTEC_T1M-10-F-SH-L-K
J4: STX-3; LINX_CONMMCX001-SMD-T
J5: BAT OUT; PinHeader_1x01_P2.54mm_Vertical
R1, R3: 1k; R_0603_1608Metric
R2, R4, R6: 10k; R_0603_1608Metric
R5: CDS; R_LDR_5.0x4.1mm_P3mm_Vertical
RF1: E32-433T37S
Temp1: AS6221(LoRa); WLCSP-6_1.4x1.0mm_P0.4mm
U1: MMC5983MA; LGA-16_3x3mm_P0.5mm
U2: TLV9001IDCK; SOT-353_SC-70-5

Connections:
+3.3V: C7.1, C10.1, FB1.2, J2.6, J2.7, R4.1, U2.5 (V+)
+3.3VA: C8.2, FB2.1, J3.3, R3.1, R6.1
+12V: C2.1, C4.1, C6.1, J3.1, RF1.3 (VCC), RF1.4 (VCC)
AS6221_SCL: J3.10, Temp1.C1 (SCL)
AS6221_SDA: J3.9, Temp1.B2 (ADD0), Temp1.C2 (SDA)
CDS_Bottom: J2.10, U2.3 (-), U2.4
GND: C1.2, C3.1, C5.1, C7.2, C10.2, H5.1, H6.1, J2.8, J2.9, R2.2, R5.2, U1.9 (GND), U1.11 (GND), U2.2 (V-)
GND2: C2.2, C4.2, C6.2, C8.1, C9.2, D2.1 (K), J1.3, J3.2, RF1.1 (GND), RF1.2 (GND), RF1.11 (GND), RF1.12 (GND), RF1.14 (GND), RF1.15 (GND), RF1.16 (GND), RF1.17 (GND), RF1.18 (GND), RF1.19 (GND), RF1.27 (GND), Temp1.A1 (VSS)
GND3: BT1.2 (-), H1.1, H2.1, H3.1, H4.1, J4.2 (Ext)
MMC5983MA_CS: J2.4, U1.4 (SPI_CS)
MMC5983MA_INT: J2.1, R2.1, U1.15 (INT)
MMC5983MA_MISO: J2.5, U1.5 (SPI_SDO)
MMC5983MA_MOSI: J2.2, U1.16 (SDA/SPI_SDI)
MMC5983MA_SCK: J2.3, U1.1 (SCL/SPI_SCK)
unnamed: ANT1.1 (A), J4.1 (In)
unnamed: BT1.1 (+), J5.1
unnamed: D1.2 (A), R3.2
unnamed: D2.2 (A), R1.2
unnamed: C9.1, FB2.2, Temp1.A2 (VDD)
unnamed: C1.1, U1.10 (CAP)
unnamed: C3.2, C5.2, FB1.1, U1.2 (VDD), U1.13 (VDDIO)
unnamed: R4.2, R5.1, U2.1 (+)
RF_M0: J3.7, RF1.10 (M0)
RF_M1: J3.8, RF1.9 (M1)
RF_RST: J3.4, RF1.5 (RESET)
RF_Rx: J1.2, J3.5, RF1.8 (RXD)
RF_State: R1.1, RF1.20 (STATE)
RF_TEMP_INT: D1.1 (K), R6.2, Temp1.B1 (Alert/ADD1)
RF_Tx: J1.1, J3.6, RF1.7 (TXD)

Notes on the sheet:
Address: 0x4A
LoRa
Magnetic Sensor
CDS CELL

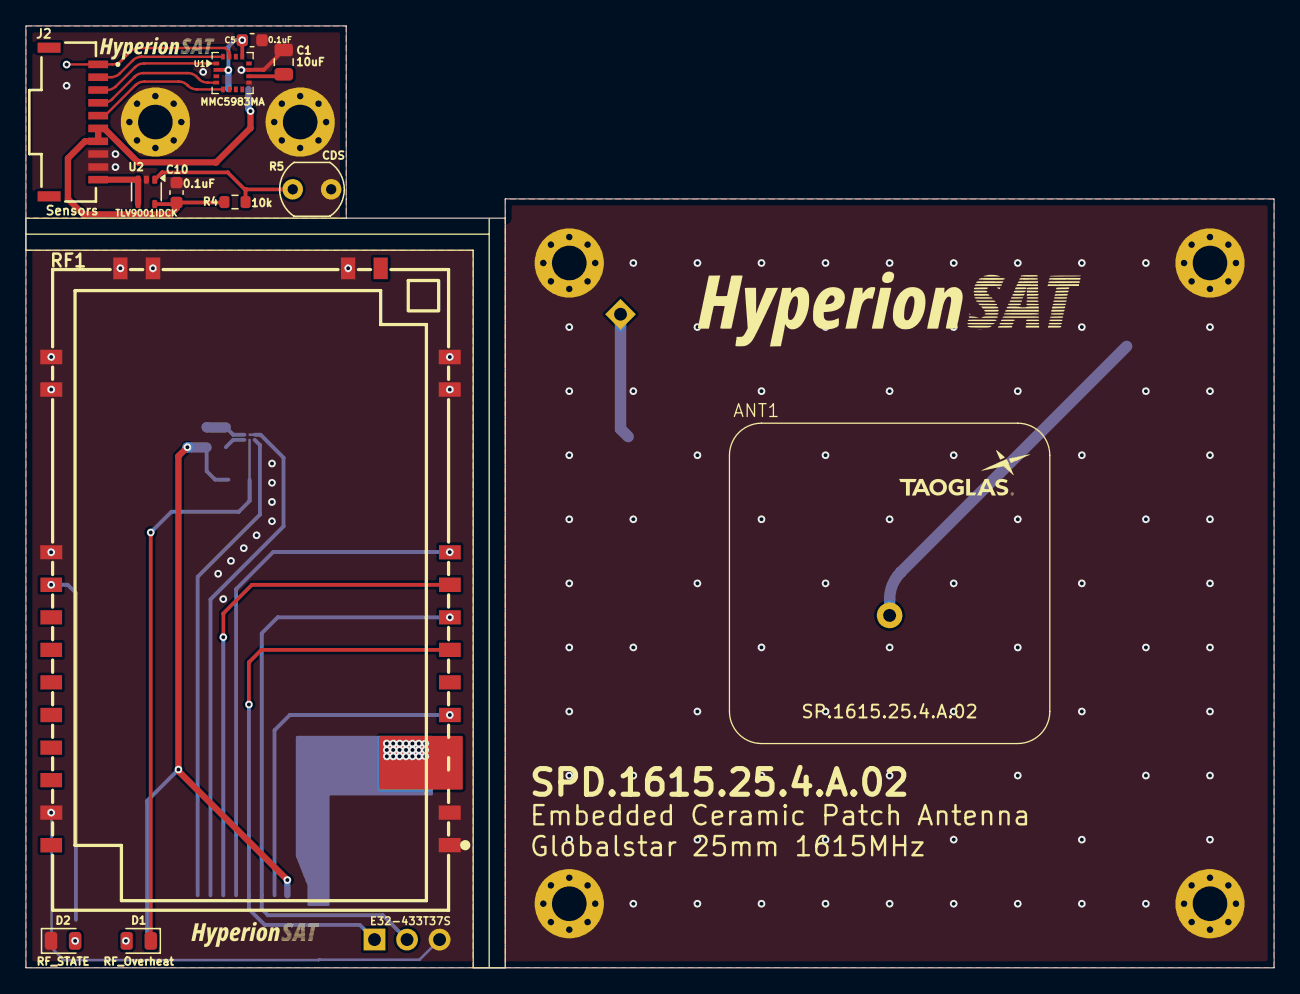
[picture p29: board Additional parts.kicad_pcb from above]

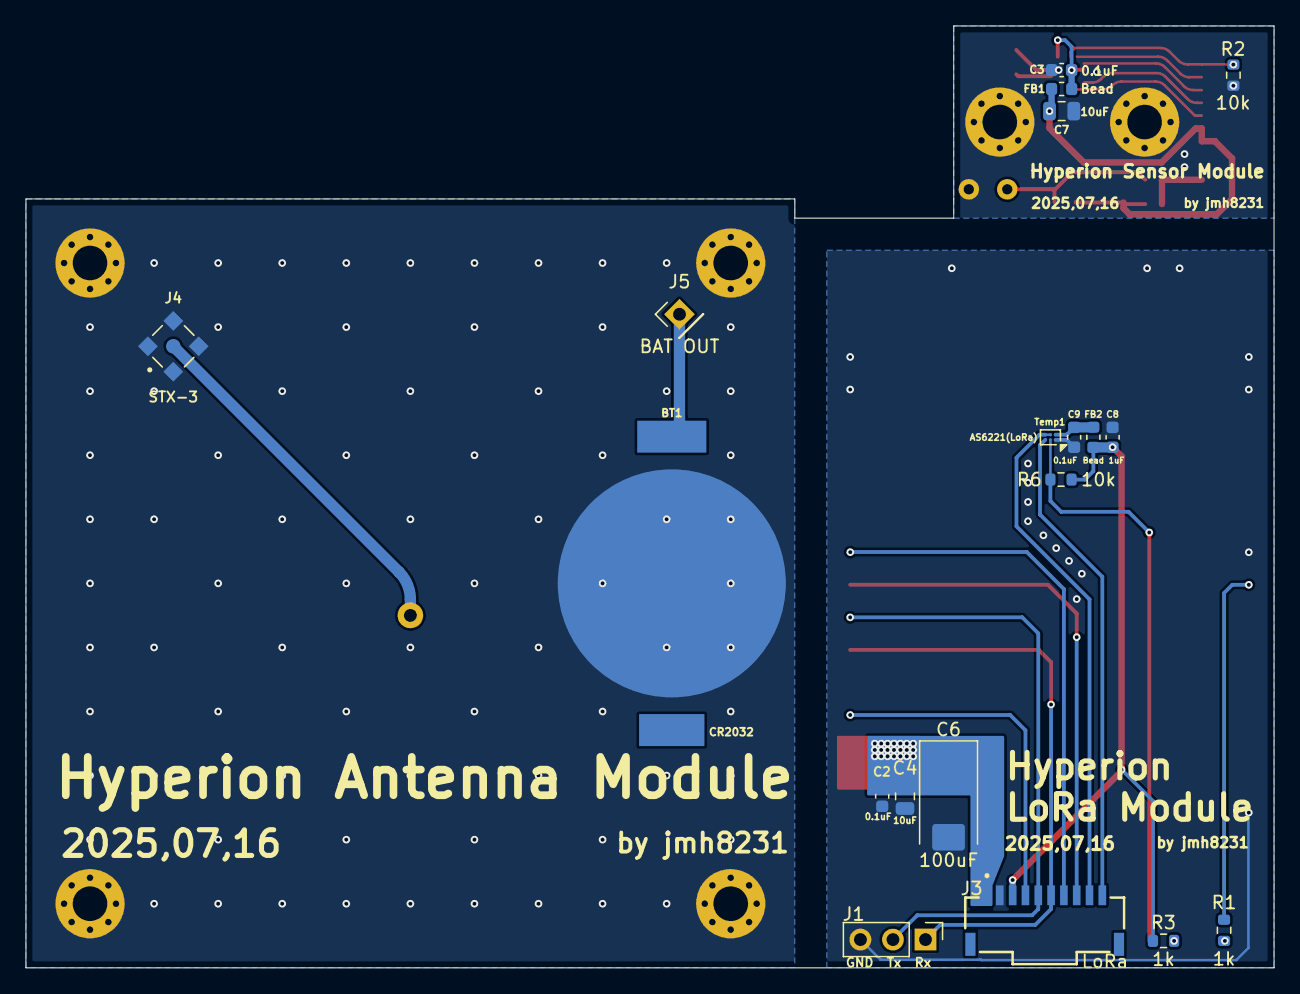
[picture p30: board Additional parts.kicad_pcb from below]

Board: 2 copper layers, 97.4 x 73.5 mm, 37 parts (19 on the bottom side), 29 nets.

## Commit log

2025-08-20 HyperionSAT Add-on
    [Additional parts.kicad_pcb, Additional parts.kicad_sch]
2025-08-20 HyperionSAT FC v1.2
    [ADC&Ref.kicad_sch, Actuator.kicad_sch, Communication.kicad_sch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]
2025-08-20 RedCheck-SDRAM Board v1.0
    [Additional Parts.kicad_sch, MCU.kicad_sch, Power.kicad_sch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]
2025-08-21 sch pdf 추가
